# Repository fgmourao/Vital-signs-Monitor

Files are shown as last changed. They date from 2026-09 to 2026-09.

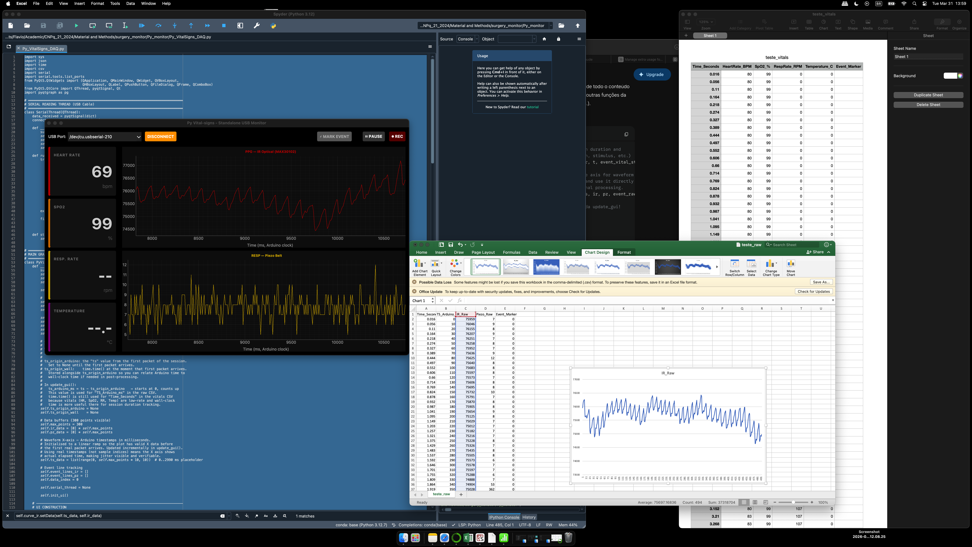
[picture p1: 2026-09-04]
Refs/interface_.png

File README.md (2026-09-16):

# Vital-signs Monitor v1.0
> **Under development**

Real-time, non-invasive physiological monitoring during experimental surgeries, stereotaxic procedures, and deep anaesthesia protocols in small rodents. ATmega2560 acquisition board controlled by a Python/PyQt5 application over USB, with simultaneous Wi-Fi browser dashboard via an on-board ESP8266.

---

## Overview

Four physiological parameters are acquired simultaneously:

- **Heart Rate** — MAX30102 optical sensor (IR channel), SparkFun `checkForBeat()` peak detector, rolling mean over N=6 beats
- **SpO2** — MAX30102 Red + IR channels, Maxim `spo2_algorithm` (sliding window: retain 75, refill 25 per update)
- **Respiratory Rate** — respiratory sensor at A0 (piezo film or FSR406 pressure sensor), software Schmitt trigger with adaptive envelope calibration every 2 s
- **Core Temperature** — NTC 100 kΩ rectal thermistor (A1), Beta equation conversion

All parameters are streamed at 100 Hz to the Python DAQ via USB-Serial and to a browser dashboard via WebSocket over Wi-Fi.

---

## Architecture

```
ATmega2560 (RobotDyn Mega+WiFi)
      │
      ├─ Serial0 (USB, 115200) ────────────────────────────────────────────────
      │        ↕ bidirectional JSON                                            │
      │   Py_VitalSigns_DAQ.py (PyQt5)                                        │
      │        outbound: {"hr":N,"sp":N,"rr":N,"pz":N,"t":N,"ir":N,"ts":N}   │
      │        inbound:  SOH + {"cmd":"set","key":"K","val":V}                 │
      │                  SOH + {"cmd":"get"}                                   │
      │                                                                        │
      ├─ Serial3 (pins 14/15, 115200) → ESP8266 (on-board) ──────────────────
      │        JSON 100 Hz stream → WebSocket → browser dashboard             │
      │                                                                        │
      ├─ I²C (pins 20/21)                                                     │
      │        ├─ MAX30102 optical sensor (address 0x57)                      │
      │        └─ SSD1306 OLED 128×32 (address 0x3C)                          │
      │                                                                        │
      ├─ A0 — Respiratory sensor (piezo film or FSR406 pressure sensor)       │
      ├─ A1 — NTC rectal thermistor                                            │
      │                                                                        │
      └─ Free-running ADC (~9.6 kHz) + TIMER1 CTC (100 Hz)                   │
               ISR decimation and Schmitt trigger for respiratory rate
```

---

## Signal Chain

### Heart Rate and SpO2

```
MAX30102 internal (400 Hz raw)
    └─ hardware averaging 4:1 → FIFO at 100 Hz
              │
              ├─ PATH 1 — Heart Rate
              │    checkForBeat(irRaw) at 100 Hz
              │    → _process_beat(): physiological gate + outlier rejection
              │    → rolling mean N=6 → heartRate (BPM)
              │
              └─ PATH 2 — SpO2
                   software decimation × g_DECIM_RATIO (default 1)
                   → irBuffer[100] + redBuffer[100]
                   → maxim_heart_rate_and_oxygen_saturation()
                   → sliding window (retain 75, refill 25) → spO2 (%)
```

### Respiratory Rate

```
Respiratory sensor (A0)
    └─ ADC_vect free-running ~9.6 kHz (ISR)
              └─ TIMER1_COMPA_vect 100 Hz CTC (ISR)
                       └─ N=4 moving average
                                └─ software Schmitt trigger
                                         └─ adaptive envelope calibration every 2 s
                                                  └─ respRate (rpm)
```

### Respiratory Sensor Signal Conditioning (Python)

The raw ADC counts from the respiratory sensor are processed in Python before display and CSV recording:

1. **Unit conversion** — counts → mV (10-bit ADC, 5 V reference: 1 count ≈ 4.89 mV)
2. **DC baseline removal** — IIR low-pass filter (α = 0.005 @ 100 Hz, fc ≈ 0.08 Hz) tracks slow drift from animal weight and posture. Time constant ~200 s.
3. **Polarity correction** — controlled by `_INVERT_RESP` constant:
   - `True` (default): FSR406 and piezo where inspiration causes a voltage drop
   - `False`: piezo where inspiration already produces a positive peak
4. **Resp. Tare** — forces immediate convergence of the DC estimate when the animal is placed on the sensor

The same processing is applied in the browser dashboard JavaScript.

### Temporal Alignment

Both `ir` and `pz` are packed in the same JSON packet. The `"ts"` field carries `millis()` at packet serialisation time and is used by the Python DAQ as the common X-axis for both waveforms, eliminating USB transport jitter (~1–15 ms) from the recorded data.

---

## EEPROM Persistence

All mutable parameters (`g_*` variables) are saved to EEPROM on every change and restored on power-up. The first boot after a fresh firmware upload uses compile-time defaults; subsequent boots load the last saved values.

EEPROM layout (ATmega2560, 4 KB available):

| Addr | Variable | Type | Bytes |
|---|---|---|---|
| 0 | Magic byte (0xA6) | uint8_t | 1 |
| 1 | g_HR_MIN_BPM | float | 4 |
| 5 | g_HR_MAX_BPM | float | 4 |
| 9 | g_HR_OUTLIER_FRAC | float | 4 |
| 13 | g_SPO2_MIN_VALID | uint8_t | 1 |
| 14 | g_DECIM_RATIO | uint8_t | 1 |
| 15 | g_LED_BRIGHTNESS | uint8_t | 1 |
| 16 | g_SAMPLE_AVERAGE | uint8_t | 1 |
| 17 | g_ADC_RANGE | uint32_t | 4 |
| 21 | g_PULSE_WIDTH | uint16_t | 2 |
| 23 | g_CALIB_MIN_SWING | int | 4 |
| 27 | g_THRESH_INSP_FRAC | float | 4 |
| 31 | g_THRESH_EXP_FRAC | float | 4 |
| 35 | g_TEMP_MIN_C | float | 4 |
| 39 | g_TEMP_MAX_C | float | 4 |

---

## USB Protocol

Bidirectional JSON over Serial0 (115200 baud). Python prefixes every command with SOH (0x01) to halt the outbound 100 Hz stream before sending.

```
Outbound (100 Hz):
    {"hr":N,"sp":N,"rr":N,"pz":N,"t":N.N,"ir":N,"ts":N}

Inbound — set parameter:
    SOH + {"cmd":"set","key":"HR_MAX","val":500} + \n
    → {"ack":"HR_MAX","val":500.0000}
    → {"nak":"reason"}  (on failure)

Inbound — read all parameters:
    SOH + {"cmd":"get"} + \n
    → {"ack":"HR_MIN","val":40.0000}
       {"ack":"HR_MAX","val":800.0000}
       ... (one line per parameter)
```

### Configurable Parameters

| Key | Variable | Module | Description |
|---|---|---|---|
| `HR_MIN` | g_HR_MIN_BPM | MAX30102 | HR lower physiological gate (BPM) |
| `HR_MAX` | g_HR_MAX_BPM | MAX30102 | HR upper physiological gate (BPM) |
| `HR_OUTLIER` | g_HR_OUTLIER_FRAC | MAX30102 | Outlier rejection fraction (0.10–0.70) |
| `SPO2_MIN` | g_SPO2_MIN_VALID | MAX30102 | Minimum accepted SpO2 (%) |
| `DECIM_RATIO` | g_DECIM_RATIO | MAX30102 | SpO2 software decimation (1, 2, or 4) |
| `LED` | g_LED_BRIGHTNESS | MAX30102 | LED drive current (1–255) — reruns sensor setup |
| `ADC_RANGE` | g_ADC_RANGE | MAX30102 | ADC full-scale (2048/4096/8192/16384) — reruns setup |
| `SAMPLE_AVG` | g_SAMPLE_AVERAGE | MAX30102 | Hardware averaging per FIFO entry — reruns setup |
| `PULSE_WIDTH` | g_PULSE_WIDTH | MAX30102 | LED pulse width (69/118/215/411 µs) — reruns setup |
| `CALIB_SWING` | g_CALIB_MIN_SWING | monitor | Minimum respiratory sensor swing (mV) for valid calibration |
| `THRESH_INSP` | g_THRESH_INSP_FRAC | monitor | Inspiration threshold fraction (0.40–0.85) |
| `THRESH_EXP` | g_THRESH_EXP_FRAC | monitor | Expiration threshold fraction (0.20–0.70) |
| `TEMP_MIN` | g_TEMP_MIN_C | monitor | Temperature lower physiological gate (°C) |
| `TEMP_MAX` | g_TEMP_MAX_C | monitor | Temperature upper physiological gate (°C) |

---

## Wi-Fi Dashboard

The ESP8266 creates a Wi-Fi access point (`SSID: Vital_Signs_Web_Monitor`) and serves an HTML dashboard at `http://192.168.4.1`. A WebSocket server on port 81 forwards the 100 Hz JSON stream to connected browsers. The browser applies the same respiratory signal conditioning as the Python DAQ (mV conversion, DC removal, polarity correction).

Multi-client dispatch:
- **Primary client** (first to connect): receives every packet → 100 Hz
- **Secondary clients** (subsequent): receive 1 in 4 packets → 25 Hz

---

## Python Application

### Requirements

```
pip install pyserial PyQt5 pyqtgraph scipy numpy
```

Python 3.8 or later. Compatible with Spyder IDE.

### Features

- Real-time scrolling waveform display (IR-PPG and respiratory sensor)
- Numeric readouts: HR, SpO2, respiratory rate, core temperature
- Arduino timestamp (`"ts"`) used as the common X-axis — eliminates USB transport jitter from recorded data
- **Settings panel** — runtime adjustment of all sensor and algorithm parameters without recompilation; changes saved to EEPROM automatically; values auto-synced from Arduino on connect
- **Help panel** — parameter reference with species-specific suggested values and tooltips on every field
- **FFT viewer** — live power spectral density for both IR-PPG and respiratory channels (Welch method, configurable window and segment length)
- **Resp. Tare** — instant respiratory sensor baseline zeroing; cancels animal weight offset without waiting for IIR filter convergence
- **Event marker** — intra-session surgical event marking with visual timeline markers on both waveforms
- **CSV recording** split into two files:
  - `*_vitals.csv` — low-rate physiological values, wall-clock time axis
  - `*_raw.csv` — high-rate conditioned waveform samples, Arduino timestamp axis (`TS_Arduino_ms`)
- Pause / Resume without disconnecting

### CSV Output Format

**`*_vitals.csv`**

| Column | Description |
|---|---|
| Time_Seconds | Wall-clock elapsed time since REC start (s) |
| HeartRate_BPM | HR from MAX30102 ring buffer (BPM) |
| SpO2_% | SpO2 from Maxim algorithm (%) |
| RespRate_RPM | Respiratory rate from sensor detector (rpm) |
| Temperature_C | NTC rectal temperature (°C) |
| Event_Marker | "Event Start" on marked rows |

**`*_raw.csv`**

| Column | Description |
|---|---|
| Time_Seconds | Wall-clock elapsed time — for cross-reference only |
| TS_Arduino_ms | Arduino millis(), normalised to 0 at REC start — **use this as the time axis for signal analysis** |
| IR_Raw | Raw IR count from MAX30102 FIFO (counts, 18-bit) |
| Resp_mV | Respiratory sensor signal in mV — DC-removed and polarity-corrected; inspiration = positive peak. NOT the raw ADC value. |
| Event_Marker | 1 on event rows, 0 otherwise |

---

## Respiratory Sensor

The system is compatible with two sensor types connected to A0 via a voltage divider (R_fixed in series to VCC):

| Sensor type | R_fixed | Notes |
|---|---|---|
| FSR406 pressure sensor | 10 kΩ | Set `_INVERT_RESP = True`. Place under the animal. Target DC ~2500 mV with animal weight. |
| Piezo film sensor | Depends on interface circuit | Set `_INVERT_RESP` based on observed polarity. Inherently AC — Resp. Tare less critical. |

**Optimal operating point:** DC level ≈ 2500 mV (mid-range) with the animal positioned. If DC is below 1000 mV, reduce R_fixed. If above 4000 mV, increase R_fixed. Adjust Calib Min Swing (default 586 mV) downward for animals with shallow breathing.

---

## Species Reference Values

| Parameter | Human (bench) | Rat (anaest.) | Mouse (anaest.) |
|---|---|---|---|
| HR Min | 40 BPM | 200 BPM | 250 BPM |
| HR Max | 200 BPM | 500 BPM | 800 BPM |
| LED Brightness | 80 | 40–60 | 20–40 |
| ADC Range | 16384 | 4096 | 2048–4096 |
| Sample Average | 4 | 1–4 | 1–2 |
| Pulse Width | 215 µs | 215–411 µs | 215–411 µs |

Target IR raw DC level: 50,000–130,000 counts (20–50% of ADC full-scale). Verify in the waveform plot after positioning the sensor.

---

## Design Tradeoffs

**[T1] DECIM_RATIO = 1**
The Maxim `spo2_algorithm.cpp` FIR filters were designed for 25 Hz input (DECIM_RATIO = 4). With DECIM_RATIO = 1 the algorithm receives 100 Hz. Human bench tests show physiologically correct SpO2 (97–99%). Performance at rodent cardiac frequencies (300–600 BPM) is untested — if systematic SpO2 overestimation (e.g. constant 100%) is observed, increase DECIM_RATIO to 4 via Settings.

**[T2] checkForBeat() with hardware-averaged signal**
The SparkFun `checkForBeat()` detector was calibrated for unaveraged signals. With `sampleAverage = 4` the AC component is smoothed before detection. If HR detection fails on rodents, reduce `sampleAverage` to 1 via Settings to restore full AC amplitude at 400 Hz.

**[T3] ADC Range**
`adcRange = 16384` is required for human fingertip at LED = 80 to avoid saturation (IR DC reaches 262,143 = 18-bit ceiling). For rodent thin tissue, try `adcRange = 4096` and verify IR raw in the waveform plot.

**[T4] IIR DC baseline convergence**
The respiratory signal DC filter has a time constant of ~200 s at 100 Hz. When the animal is first placed on the sensor, the display may appear shifted until the filter converges. Use **Resp. Tare** to force immediate convergence.

**[T5] SparkFun library internal buffer — STORAGE_SIZE**
The SparkFun MAX3010x library uses an internal ring buffer (`STORAGE_SIZE`) to hold FIFO data between `check()` calls. The default value of 4 samples causes silent data loss whenever `loop()` is delayed beyond ~40 ms (e.g. by the OLED display task), producing irregular sample spacing in `irBuffer[]` and `redBuffer[]`. This distorts the Maxim FIR filters and typically causes SpO2 to read 100% or HR to be erratic. This project set `STORAGE_SIZE = 64` by editing `MAX30105.h` at `~/Documents/Arduino/libraries/SparkFun_MAX3010x_Sensor_Library/src/MAX30105.h`

**[T6] SpO2 reference values**
The Maxim `spo2_algorithm` lookup table was calibrated for adult human fingertip measurements. In anaesthetised rodents, SpO2 values of 88–95% have been reported in the literature. If the monitor reads 99–100% during rodent anaesthesia, this may reflect algorithm miscalibration (next steps...)

---

## Hardware Requirements

| Component | Specification |
|---|---|
| Microcontroller | RobotDyn Mega+WiFi (ATmega2560 + ESP8266) |
| Optical sensor | MAX30102 breakout — I²C, address 0x57, 3.3 V |
| Display | SSD1306 OLED 128×32 — I²C, address 0x3C |
| Respiratory sensor | Piezo film or FSR406 → A0 (voltage divider with R_fixed to VCC) |
| Temperature probe | NTC 100 kΩ rectal thermistor → A1 (series 100 kΩ to VCC) |
| USB | ATmega2560 USB-Serial bridge (Arduino IDE upload port) |

---

## Files

| File | Description |
|---|---|
| `surgery_monitor.ino` | Main sketch — ISRs, task scheduler, OLED display, monitor_set_param() |
| `surgery_monitor_MAX30102.ino` | MAX30102 HR + SpO2, EEPROM persistence, max30102_set_param() |
| `Py_Vital-Signs.ino` | USB bidirectional stream — 100 Hz outbound + SOH command parser |
| `surgery_monitor_web_server.ino` | Serial3 → ESP8266 JSON bridge at 100 Hz |
| `ESP8266_VitalSigns_Server.ino` | ESP8266 firmware — Wi-Fi AP, HTTP dashboard, WebSocket multi-client |
| `MAX30102_Diagnostic_Tool.ino` | Standalone diagnostic sketch — IR waveform and SpO2 algorithm analysis |
| `Py_VitalSigns_DAQ.py` | Python DAQ application (PyQt5 + pyqtgraph) |
| `fft_vitalsigns.py` | Live PSD viewer — Welch method for HR and respiratory spectral analysis |

Arduino library dependencies (install via Arduino IDE Library Manager):
- **SparkFun MAX3010x Pulse and Proximity Sensor Library** ⚠️ requires manual modification (see [T5])
- **U8g2** (Oliver Kraus)
- **WebSockets** (Markus Sattler) — ESP8266 only

### Library Configuration

The SparkFun MAX3010x library requires one manual edit before compiling:

**File:** `~/Documents/Arduino/libraries/SparkFun_MAX3010x_Sensor_Library/src/MAX30105.h`

Locate and change:
```cpp
#define STORAGE_SIZE 4
```
to:
```cpp
#define STORAGE_SIZE 64  // required — default of 4 causes silent sample loss
```

This setting controls the size of the library's internal ring buffer. With the default of 4, any `loop()` delay beyond ~40 ms silently discards samples before they reach the HR and SpO2 algorithms, causing SpO2 to read 100% and HR to be erratic. See [T5] for the technical explanation.

---

## Known Limitations

- HR and SpO2 values are not validated against a calibrated reference instrument.
- SpO2 may read 100% consistently if `DECIM_RATIO = 1` (increase to 4 via Settings) or if the SparkFun library `STORAGE_SIZE` is not set to 64 (see [T5]).
- The `_debug_serial()` diagnostic output is plain text and incompatible with the Python DAQ. Use only with the Arduino IDE Serial Monitor when the Python application is not connected.
- If the USB cable is disconnected during a recording session, the CSV files may be incomplete. Always stop recording before disconnecting.
- Primary Wi-Fi client assignment is first-connect order. If a secondary workstation connects before the primary, it will receive 25 Hz instead of 100 Hz.
- The Resp. Tare is session-only — it resets if the application is restarted or the connection is toggled.

---

## Author

**v1.0 (2026)**
Flavio Afonso Goncalves Mourao — [mourao.fg@gmail.com](mailto:mourao.fg@gmail.com)
*CNPq/MCTI/FNDCT Nº 21/2024 — Processo 446467/2024-3*
*Federal University of Minas Gerais, Brazil*

---

*Last update: September 2026*

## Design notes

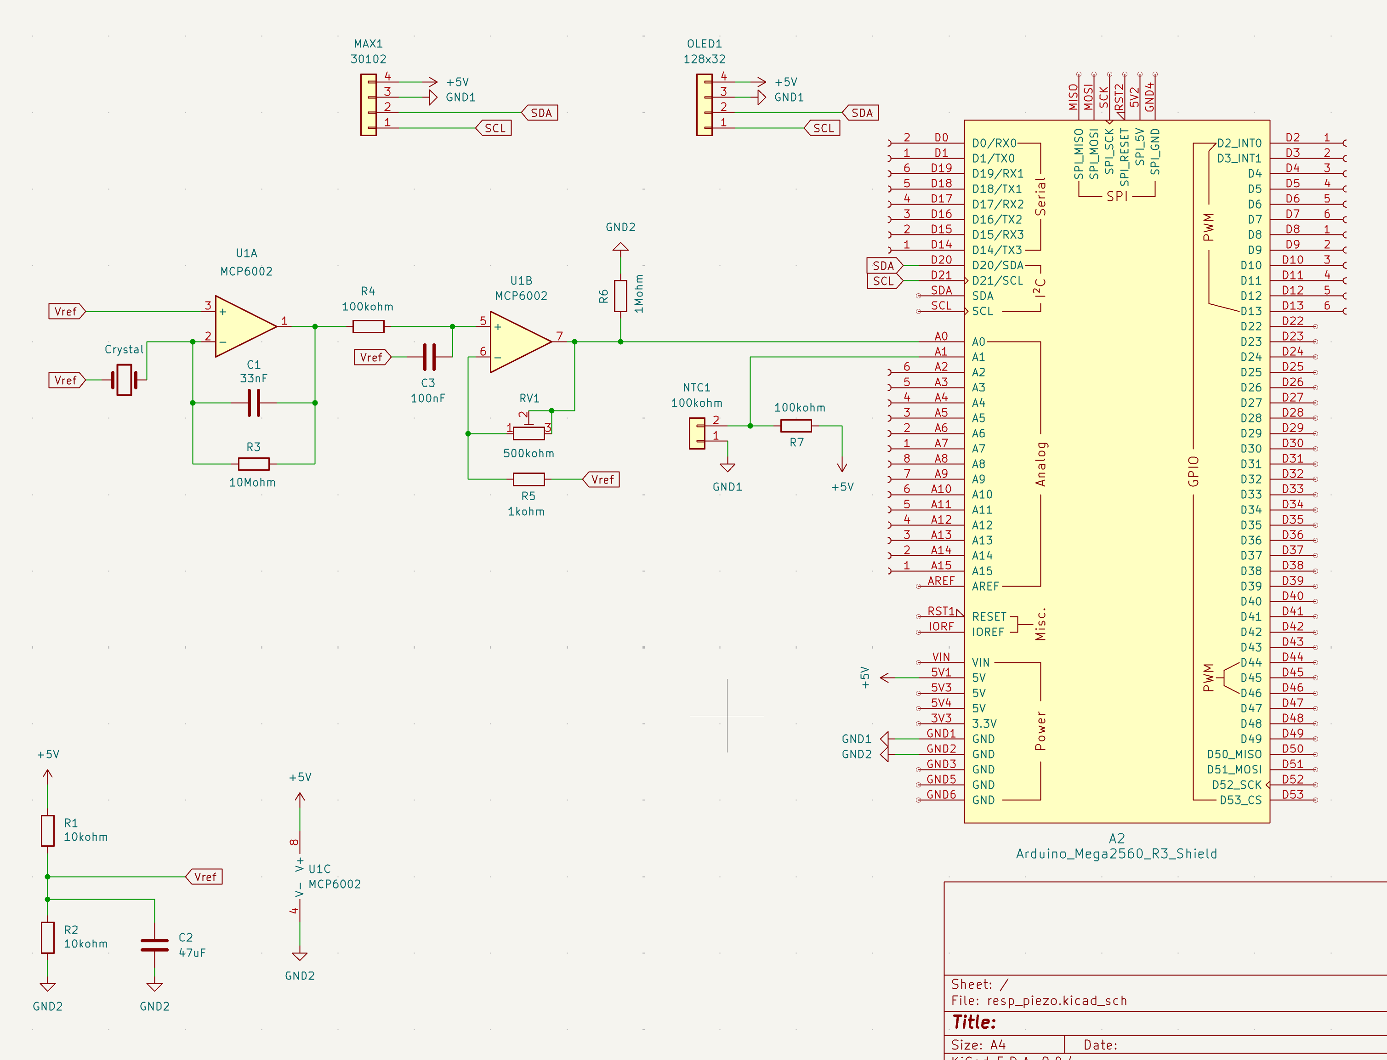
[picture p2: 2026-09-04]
Resp_piezo_circuit/Circuit_.png

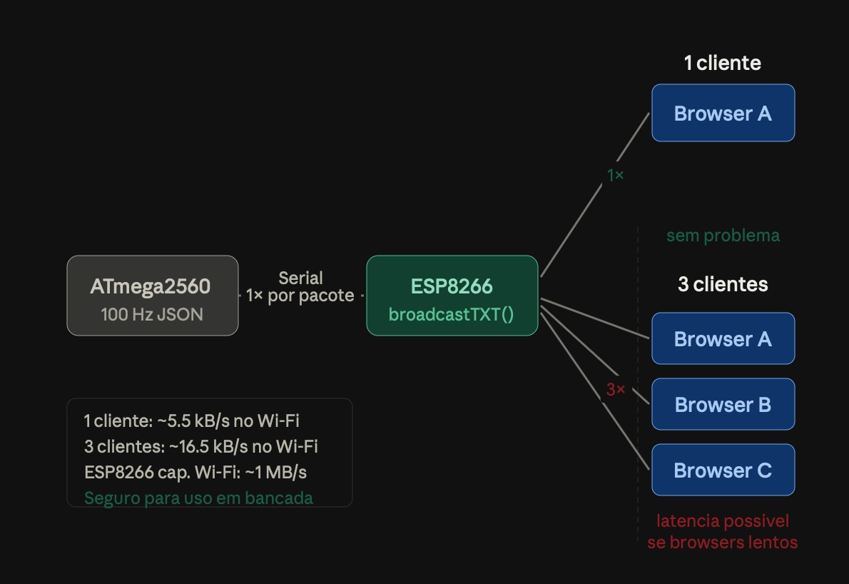
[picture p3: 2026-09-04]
Refs/ESP_client.png

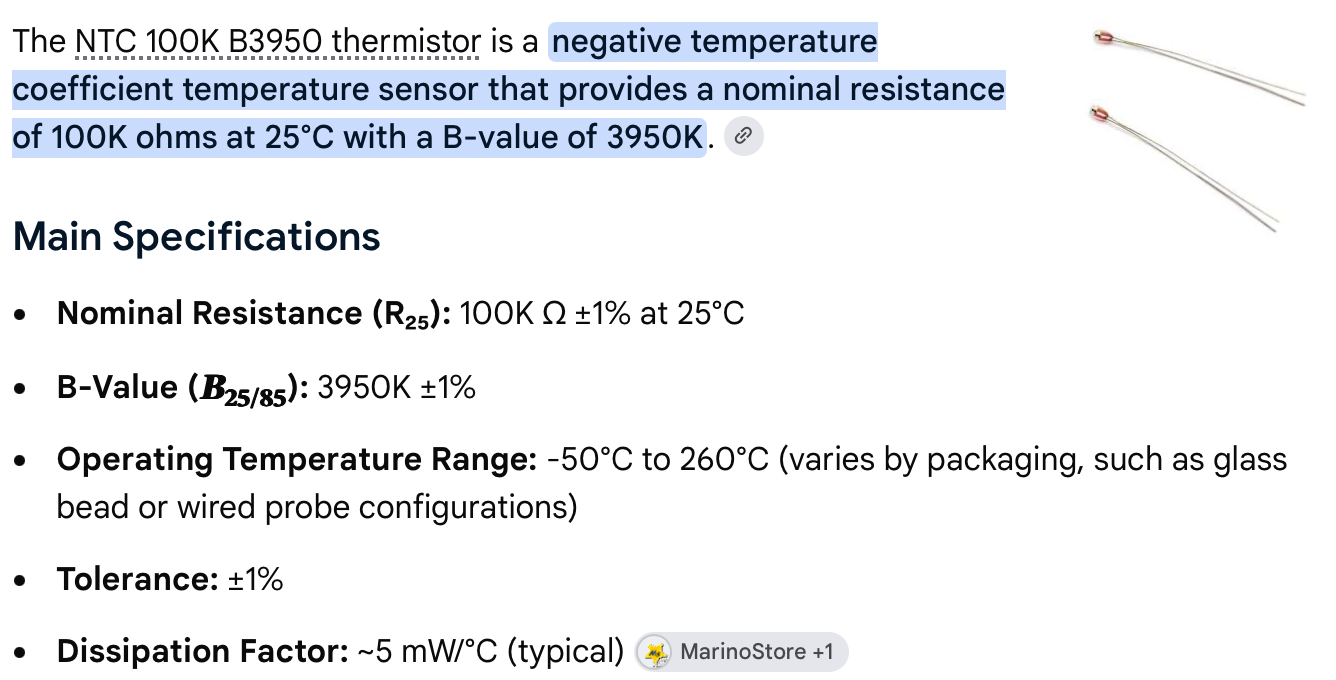
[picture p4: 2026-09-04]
Refs/Termistor NTC B3950 100K .png

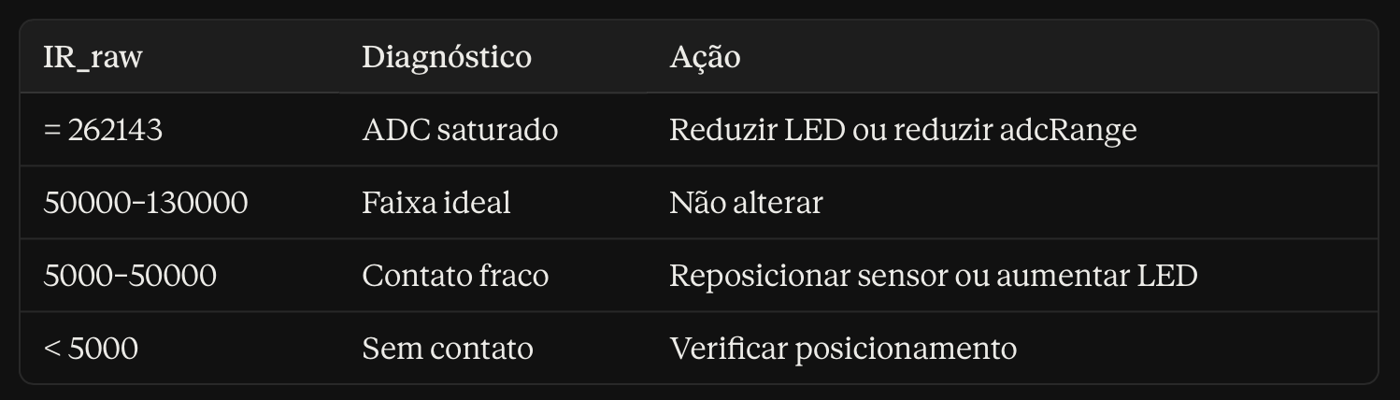
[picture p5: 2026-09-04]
Refs/IR_value.png

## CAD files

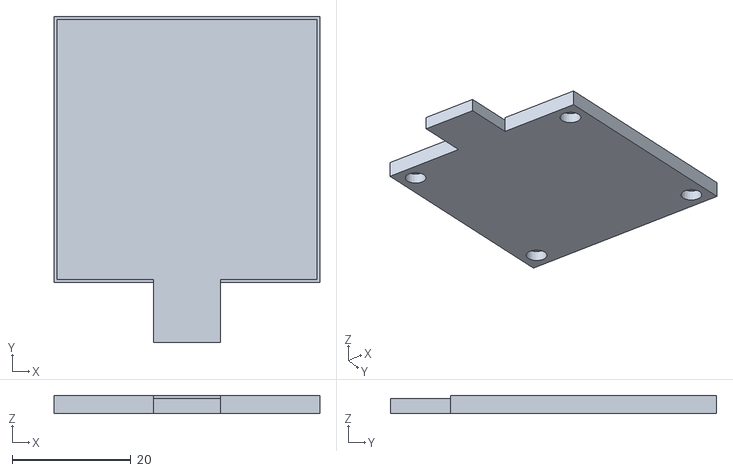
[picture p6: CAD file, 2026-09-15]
MAX30102_3D_case/FSR406/FSR406_base_magnets.stl
44.7 x 54.8 x 3.04

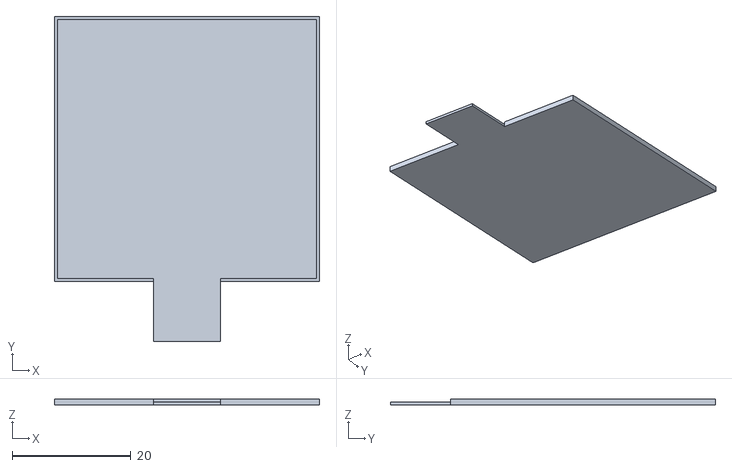
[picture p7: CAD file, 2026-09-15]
MAX30102_3D_case/FSR406/FSR406_base_thin.stl
44.7 x 54.8 x 1.04

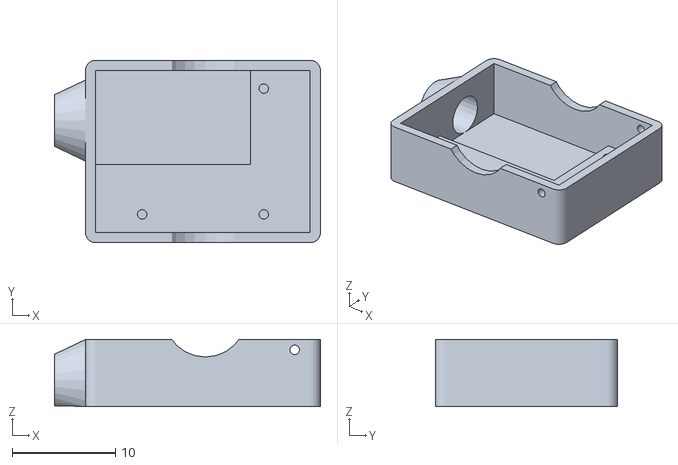
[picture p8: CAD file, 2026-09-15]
MAX30102_3D_case/MAX30102/MAX30102_case_bottom.stl
25.8 x 17.7 x 6.50

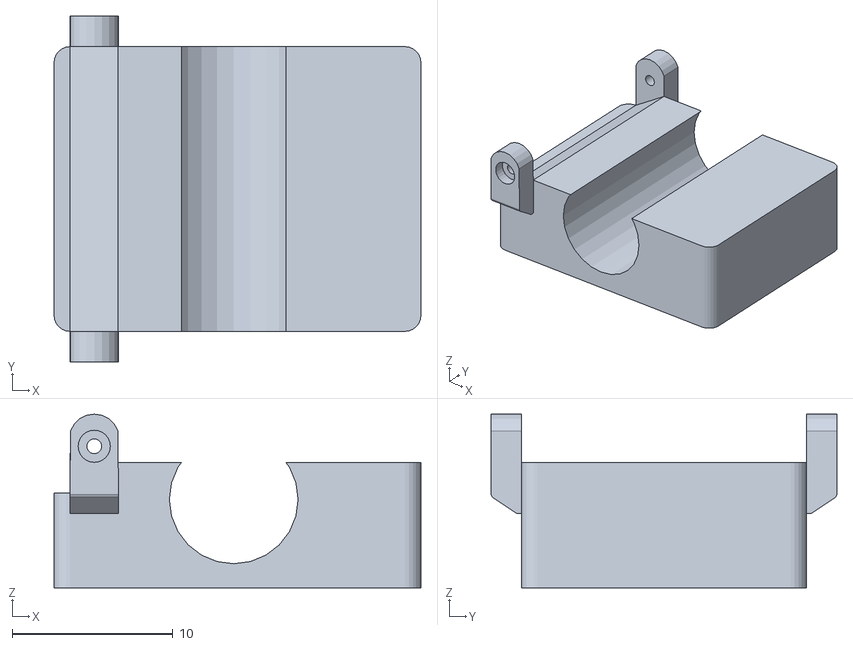
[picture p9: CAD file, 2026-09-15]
MAX30102_3D_case/MAX30102/MAX30102_case_top.stl
22.8 x 21.5 x 10.8

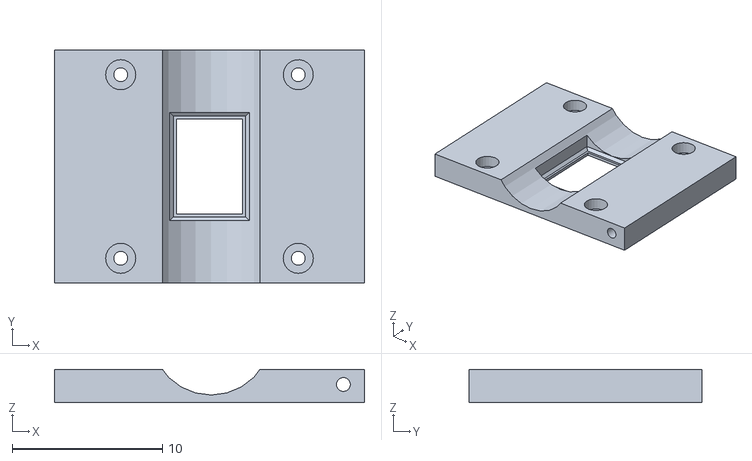
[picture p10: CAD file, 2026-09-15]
MAX30102_3D_case/MAX30102/MAX30102_case_middle.stl
20.6 x 15.5 x 2.20

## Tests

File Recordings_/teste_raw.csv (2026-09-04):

Time_Seconds | TS_Arduino_ms | IR_Raw | Piezo_Raw | Event_Marker
0.016 | 0 | 75959 | 7 | 0
0.056 | 10 | 76046 | 9 | 0
0.11 | 20 | 76155 | 8 | 0
0.164 | 30 | 76207 | 9 | 0
0.218 | 40 | 76251 | 7 | 0
0.274 | 50 | 76258 | 8 | 0
0.327 | 60 | 75952 | 7 | 0
0.389 | 70 | 75636 | 9 | 0
0.444 | 80 | 75625 | 12 | 0
0.497 | 90 | 75640 | 8 | 0
0.552 | 100 | 75683 | 8 | 0
0.606 | 110 | 75597 | 8 | 0
0.66 | 120 | 75573 | 7 | 0
0.714 | 130 | 75606 | 8 | 0
0.769 | 140 | 75695 | 8 | 0
0.824 | 150 | 75732 | 10 | 0
0.878 | 160 | 75791 | 7 | 0
0.932 | 170 | 75870 | 8 | 0
0.987 | 180 | 75905 | 8 | 0
1.041 | 190 | 75654 | 9 | 0
1.095 | 200 | 75125 | 8 | 0
1.149 | 210 | 75029 | 7 | 0
1.203 | 220 | 75012 | 7 | 0
1.257 | 230 | 75182 | 7 | 0
1.321 | 240 | 75216 | 7 | 0
1.375 | 250 | 75228 | 8 | 0
1.429 | 260 | 75326 | 7 | 0
1.483 | 270 | 75435 | 8 | 0
1.537 | 280 | 75505 | 8 | 0
1.592 | 290 | 75573 | 6 | 0
1.646 | 300 | 75578 | 7 | 0
1.701 | 310 | 75597 | 7 | 0
1.755 | 320 | 75288 | 6 | 0
1.809 | 330 | 74888 | 7 | 0
1.864 | 340 | 74904 | 53 | 0
1.919 | 350 | 75028 | 362 | 0
1.973 | 360 | 75218 | 453 | 0
2.027 | 370 | 75197 | 747 | 0
2.082 | 380 | 75194 | 751 | 0
2.136 | 390 | 75310 | 753 | 0
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

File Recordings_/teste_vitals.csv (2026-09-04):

Time_Seconds | HeartRate_BPM | SpO2_% | RespRate_RPM | Temperature_C | Event_Marker
0.016 | 80 | 99 | 0 | 0
0.056 | 80 | 99 | 0 | 0
0.11 | 80 | 99 | 0 | 0
0.164 | 80 | 99 | 0 | 0
0.218 | 80 | 99 | 0 | 0
0.274 | 80 | 99 | 0 | 0
0.327 | 80 | 99 | 0 | 0
0.389 | 80 | 99 | 0 | 0
0.444 | 80 | 99 | 0 | 0
0.497 | 80 | 99 | 0 | 0
0.552 | 80 | 99 | 0 | 0
0.606 | 80 | 99 | 0 | 0
0.66 | 80 | 99 | 0 | 0
0.714 | 80 | 99 | 0 | 0
0.769 | 80 | 99 | 0 | 0
0.824 | 80 | 99 | 0 | 0
0.878 | 80 | 99 | 0 | 0
0.932 | 80 | 99 | 0 | 0
0.987 | 80 | 99 | 0 | 0
1.041 | 80 | 99 | 0 | 0
1.095 | 80 | 99 | 0 | 0
1.149 | 80 | 99 | 0 | 0
1.203 | 80 | 99 | 0 | 0
1.257 | 80 | 99 | 0 | 0
1.321 | 80 | 99 | 0 | 0
1.375 | 80 | 99 | 0 | 0
1.429 | 80 | 99 | 0 | 0
1.483 | 80 | 99 | 0 | 0
1.537 | 80 | 99 | 0 | 0
1.592 | 80 | 99 | 0 | 0
1.646 | 80 | 99 | 0 | 0
1.701 | 80 | 99 | 0 | 0
1.755 | 80 | 99 | 0 | 0
1.809 | 80 | 99 | 0 | 0
1.864 | 80 | 99 | 0 | 0
1.919 | 80 | 99 | 0 | 0
1.973 | 80 | 99 | 0 | 0
2.027 | 80 | 99 | 0 | 0
2.082 | 80 | 99 | 0 | 0
2.136 | 80 | 99 | 0 | 0
2.19 | 80 | 99 | 0 | 0
2.252 | 80 | 99 | 0 | 0
2.306 | 80 | 99 | 0 | 0
2.362 | 80 | 99 | 0 | 0
2.416 | 80 | 99 | 0 | 0
2.471 | 80 | 99 | 0 | 0
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

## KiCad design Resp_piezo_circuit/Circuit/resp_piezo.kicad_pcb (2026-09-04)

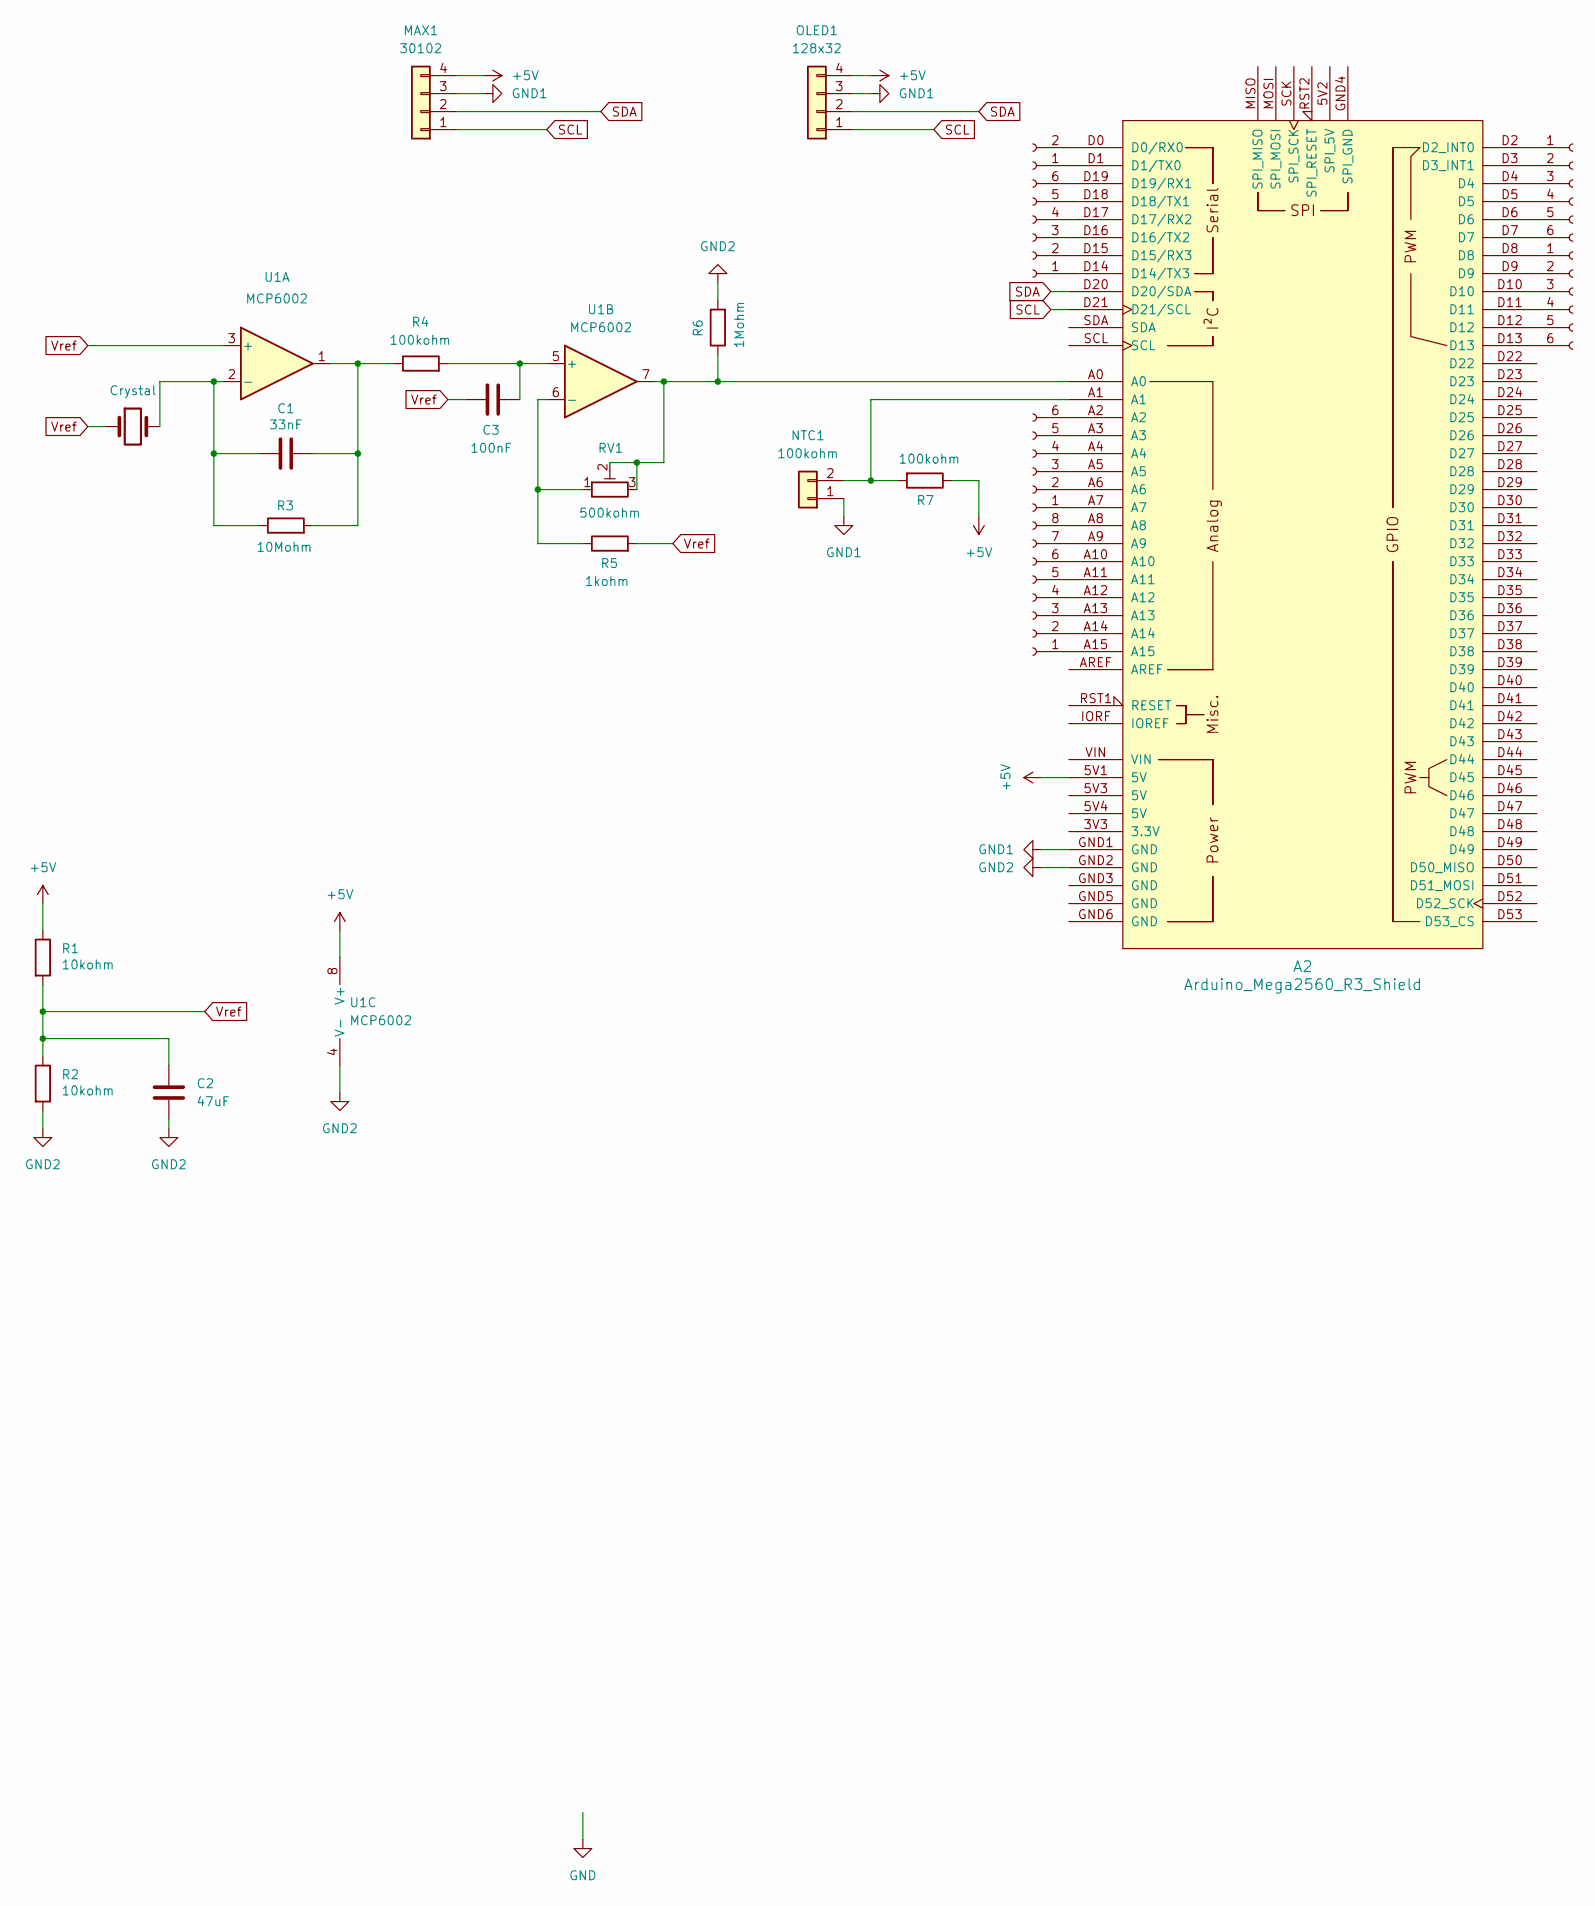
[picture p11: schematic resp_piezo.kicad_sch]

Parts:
A2: Arduino_Mega2560_R3_Shield
C1: 33nF; C_0805_2012Metric
C2: 47uF; C_0805_2012Metric
C3: 100nF; C_0805_2012Metric
J1, J3, J4: Conn_01x06_Socket; PinSocket_1x06_P2.54mm_Vertical
J2: Conn_01x06_Socket; PinHeader_1x06_P2.54mm_Vertical
J5: Conn_01x08_Socket; PinHeader_1x08_P2.00mm_Vertical
J6: Conn_01x02_Socket; PinSocket_1x02_P2.00mm_Vertical
MAX1: 30102; PinSocket_1x04_P2.54mm_Vertical
NTC1: 100kohm; PinSocket_1x02_P2.54mm_Vertical
OLED1: 128x32; PinSocket_1x04_P2.54mm_Vertical
R1, R2: 10kohm; R_0805_2012Metric
R3: 10Mohm; R_0805_2012Metric
R4, R7: 100kohm; R_0805_2012Metric
R5: 1kohm; R_0805_2012Metric
R6: 1Mohm; R_0805_2012Metric
RV1: 500kohm; PinHeader_1x03_P2.54mm_Vertical
U1: MCP6002; DIP787W46P254L927H533Q8
Y1: Crystal; PinHeader_1x02_P2.54mm_Vertical

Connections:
+5V: A2.5V1 (5V), MAX1.4, OLED1.4, R1.1, R7.1, U1.8 (V+)
GND1: A2.GND1 (GND), MAX1.3, NTC1.1, OLED1.3
GND2: A2.GND2 (GND), C2.2, R2.2, R6.2, U1.4 (V-), U1.9 (V-)
unnamed: A2.D0 (D0/RX0), J6.2
unnamed: A2.D1 (D1/TX0), J6.1
unnamed: A2.D2 (D2_INT0), J1.1
unnamed: A2.D3 (D3_INT1), J1.2
unnamed: A2.D14 (D14/TX3), J3.1
unnamed: A2.D15 (D15/RX3), J3.2
unnamed: A2.D16 (D16/TX2), J3.3
unnamed: A2.D17 (D17/RX2), J3.4
unnamed: A2.D18 (D18/TX1), J3.5
unnamed: A2.D19 (D19/RX1), J3.6
unnamed: A2.A0, R6.1, RV1.2, RV1.3, U1.7
unnamed: C1.2, R3.2, R4.1, U1.1
unnamed: A2.D4, J1.3
unnamed: A2.D5, J1.4
unnamed: A2.D6, J1.5
unnamed: A2.D7, J1.6
unnamed: A2.D8, J2.1
unnamed: A2.D9, J2.2
unnamed: A2.D10, J2.3
unnamed: A2.D11, J2.4
unnamed: A2.D12, J2.5
unnamed: A2.D13, J2.6
unnamed: A2.A7, J4.1
unnamed: A2.A6, J4.2
unnamed: A2.A5, J4.3
unnamed: A2.A4, J4.4
unnamed: A2.A3, J4.5
unnamed: A2.A2, J4.6
unnamed: A2.A15, J5.1
unnamed: A2.A14, J5.2
unnamed: A2.A13, J5.3
unnamed: A2.A12, J5.4
unnamed: A2.A11, J5.5
unnamed: A2.A10, J5.6
unnamed: A2.A9, J5.7
unnamed: A2.A8, J5.8
unnamed: A2.A1, NTC1.2, R7.2
unnamed: C1.1, R3.1, U1.2 (-), Y1.2
unnamed: C3.2, R4.2, U1.5 (+)
unnamed: R5.1, RV1.1, U1.6 (-)
SCL: A2.D21 (D21/SCL), MAX1.1, OLED1.1
SDA: A2.D20 (D20/SDA), MAX1.2, OLED1.2
Vref: C2.1, C3.1, R1.2, R2.1, R5.2, U1.3 (+), Y1.1

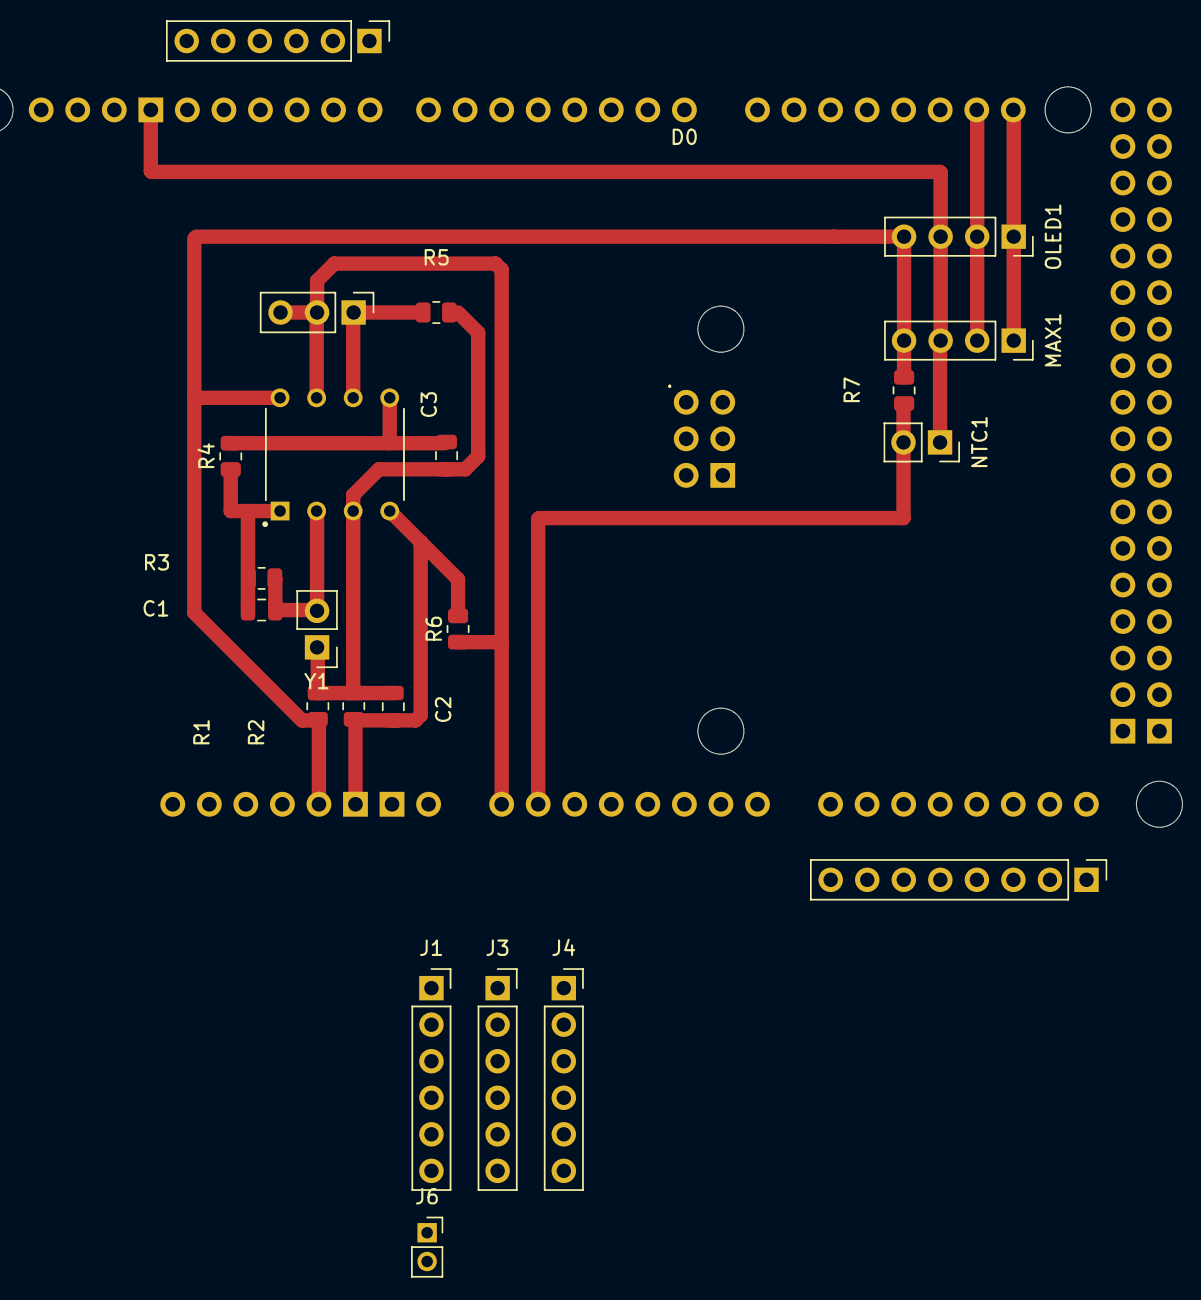
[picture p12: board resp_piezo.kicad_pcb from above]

Board: 2 copper layers, 23 parts (0 on the bottom side), 46 nets.

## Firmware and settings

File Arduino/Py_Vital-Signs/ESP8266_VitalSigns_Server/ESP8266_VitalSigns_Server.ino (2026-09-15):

/**
 * @file    ESP8266_VitalSigns_Server.ino
 * PROJECT: Vital-signs monitor — small rodents (rat / mouse)
 * @version 3.0 (Multi-client)
 * @author  Flávio Mourão — Mar, 2026
 *
 * ═══════════════════════════════════════════════════════════════════════════════
 * MODULE RESPONSIBILITY
 * ═══════════════════════════════════════════════════════════════════════════════
 * This sketch runs on the ESP8266 co-processor of the RobotDyn Mega+WiFi board.
 * It performs three tasks:
 *
 *   1. Wi-Fi Access Point — creates a local network (no internet required).
 *   2. HTTP Server (port 80) — serves the embedded HTML/JS dashboard to browsers.
 *   3. WebSocket Server (port 81) — forwards JSON packets received from the
 *      ATmega2560 (via Serial) to connected browser clients.
 *
 * ═══════════════════════════════════════════════════════════════════════════════
 * CHANGES vs v2.0 — MULTI-CLIENT SUPPORT (3–5 simultaneous browsers)
 * ═══════════════════════════════════════════════════════════════════════════════
 *
 * [C1] Non-blocking Serial read (replaces readStringUntil)
 *   v2.0 used Serial.readStringUntil('\n'), which blocks the entire loop()
 *   until a full line arrives or the timeout expires. With multiple WebSocket
 *   clients generating keep-alive traffic, this caused frame accumulation and
 *   eventually client disconnections.
 *
 *   v3.0 reads one byte at a time per loop() iteration, accumulating into
 *   rxBuffer until '\n' is detected. webSocket.loop() is never blocked.
 *   Maximum latency added per loop(): one Serial.read() call (~1 µs).
 *
 * [C2] Tiered dispatch: primary client at 100 Hz, secondary clients at 25 Hz
 *   Broadcasting the full 100 Hz stream to 5 clients simultaneously would
 *   require the ESP8266 to transmit 5 × 55 bytes × 100 Hz = 27.5 kB/s on
 *   the Wi-Fi channel. While within the hardware limit (~1 MB/s), the
 *   sequential sendTXT() calls per loop() iteration would block webSocket.loop()
 *   for ~2.4 ms at 115200 baud, degrading all clients.
 *
 *   The tiered approach:
 *     Primary client (first to connect): receives every packet → 100 Hz
 *     Secondary clients (subsequent):   receive 1 in 4 packets → 25 Hz
 *
 *   25 Hz is sufficient for numeric readout updates and smooth waveform
 *   display on secondary monitors (human visual persistence ~40 ms).
 *   The primary client (e.g., the surgeon's workstation) retains full
 *   100 Hz resolution for waveform detail.
 *
 * [C3] WebSocket event handler
 *   webSocket.onEvent() now tracks which client is the primary and clears
 *   the slot when the primary disconnects, allowing the next client to
 *   take the primary role automatically.
 *
 * ═══════════════════════════════════════════════════════════════════════════════
 * HARDWARE CONTEXT — RobotDyn Mega+WiFi
 * ═══════════════════════════════════════════════════════════════════════════════
 * On the RobotDyn board, the ESP8266 hardware UART (Serial, GPIO1/GPIO3) is
 * bridged via PCB traces to ATmega2560 Serial3 (pins 14/15). Data flows:
 *
 *   ATmega2560 Serial3 → [PCB bridge] → ESP8266 Serial.available()
 *
 * Baud rate: 115200. Must match vitalsigns_init() in surgery_monitor_web_server.ino.
 *
 * Flash this sketch using the Arduino IDE with board set to "Generic ESP8266".
 * The DIP switch bank on the RobotDyn board must be configured for ESP8266
 * programming mode during upload, then switched back for normal Mega operation.
 *
 * ═══════════════════════════════════════════════════════════════════════════════
 * NETWORK ARCHITECTURE
 * ═══════════════════════════════════════════════════════════════════════════════
 *
 *  [ATmega2560] --Serial3/115200--> [ESP8266] --Wi-Fi AP--> [Browsers]
 *
 *  Access Point:  SSID = AP_SSID (default: "Vital_Signs_Web_Monitor")
 *  Password:      AP_PASSWORD (empty = open network)
 *  AP IP address: 192.168.4.1 (ESP8266 SoftAP default)
 *
 *  Browser access: http://192.168.4.1
 *  WebSocket:      ws://192.168.4.1:81
 *
 *  Client capacity: up to WEBSOCKETS_SERVER_CLIENT_MAX (default 5 in library).
 *    - Client 0 (primary):   100 Hz full stream
 *    - Clients 1–4 (secondary): 25 Hz reduced stream
 *
 * ═══════════════════════════════════════════════════════════════════════════════
 * BANDWIDTH BUDGET (worst case: 5 clients)
 * ═══════════════════════════════════════════════════════════════════════════════
 *  Primary (1×):    65 B × 100 Hz = 6.5 kB/s
 *  Secondary (4×):  65 B × 25 Hz × 4 = 26 kB/s
 *  Total:           ~32.5 kB/s << ESP8266 Wi-Fi ~1 MB/s capacity
 *
 * ═══════════════════════════════════════════════════════════════════════════════
 * KNOWN LIMITATIONS
 * ═══════════════════════════════════════════════════════════════════════════════
 * [L1] Primary client assignment is first-connect order
 *   The first browser to open a WebSocket connection becomes the primary
 *   (100 Hz) client. If the surgeon's workstation connects second, it
 *   receives 25 Hz. Workaround: reload the primary browser first, or
 *   implement a URL parameter to request primary status (e.g. /?primary=1).
 *
 * [L2] Open Wi-Fi network
 *   AP_PASSWORD is empty by default — open network. Acceptable in a
 *   controlled lab. Set WPA2 password for environments with data governance
 *   requirements.
 *
 * [L3] No data persistence
 *   The ESP8266 holds no historical data. A browser connecting mid-session
 *   starts with an empty waveform buffer and sees no past data.
 *
 * ═══════════════════════════════════════════════════════════════════════════════
 * REQUIRED LIBRARIES
 * ═══════════════════════════════════════════════════════════════════════════════
 *   ESP8266WiFi       — bundled with ESP8266 Arduino core
 *   ESP8266WebServer  — bundled with ESP8266 Arduino core
 *   WebSocketsServer  — arduinoWebSockets by Markus Sattler (Library Manager)
 */

#include <ESP8266WiFi.h>
#include <ESP8266WebServer.h>
#include <WebSocketsServer.h>


// ── Network configuration ────────────────────────────────────────────────────

const char* AP_SSID     = "Vital_Signs_Web_Monitor";
const char* AP_PASSWORD = "";   // Empty = open network


// ── Multi-client configuration ───────────────────────────────────────────────

// Maximum clients the WebSocketsServer library supports simultaneously.
// Default in the library: 5. Increase by editing WEBSOCKETS_SERVER_CLIENT_MAX
// in WebSockets.h, but each slot consumes ~300 B of heap on the ESP8266.
static const uint8_t MAX_CLIENTS = 5;

// Rate divisor for secondary clients.
// SECONDARY_DIVISOR = 4 → secondary clients receive 1 in 4 packets = 25 Hz.
// Increase to 8 for 12.5 Hz if more than 4 secondary clients are expected.
static const uint8_t SECONDARY_DIVISOR = 4;

// Sentinel value: no primary client assigned yet.
static const uint8_t NO_PRIMARY = 255;


// ── Runtime state ────────────────────────────────────────────────────────────

// ID of the primary (100 Hz) WebSocket client.
// Set to the first client that connects; reset when that client disconnects.
static uint8_t primaryClientId = NO_PRIMARY;

// Packet counter used to throttle secondary clients.
// Incremented on every valid packet received from the ATmega2560.
static uint8_t packetCount = 0;

// Non-blocking Serial receive buffer.
// Accumulates bytes until '\n' is received, then dispatches the complete packet.
static String rxBuffer = "";


// ── Server instances ─────────────────────────────────────────────────────────

ESP8266WebServer  server(80);
WebSocketsServer  webSocket = WebSocketsServer(81);


// ── Embedded dashboard HTML/JS ───────────────────────────────────────────────
// Stored in PROGMEM (flash) to preserve heap RAM.
// Identical to v2.0 — the multi-client logic is server-side only.
// Secondary clients display at 25 Hz; all visual behaviour is unchanged.
const char index_html[] PROGMEM = R"rawliteral(
<!DOCTYPE html>
<html lang="en">
<head>
    <meta charset="UTF-8">
    <meta name="viewport" content="width=device-width, initial-scale=1.0">
    <title>Vital-Signs - Web Monitor</title>
    <style>
        * { box-sizing: border-box; margin: 0; padding: 0; }
        body { background-color: #000; color: #fff; font-family: 'Segoe UI', Tahoma, Geneva, Verdana, sans-serif; overflow: hidden; height: 100vh; }
        #header { background: #111; padding: 8px 20px; font-size: 18px; font-weight: bold; border-bottom: 2px solid #222; color: #666; display: flex; align-items: center; gap: 10px; height: 42px; }
        #status-dot { width: 10px; height: 10px; border-radius: 50%; background: #333; flex-shrink: 0; }
        #status-dot.connected { background: #0f0; }
        #client-role { font-size: 12px; color: #444; margin-left: auto; }
        .grid-container { display: flex; height: calc(100vh - 42px); }
        .sidebar { width: 260px; min-width: 200px; background: #0a0a0a; padding: 16px; display: flex; flex-direction: column; gap: 14px; border-right: 2px solid #1a1a1a; overflow: hidden; }
        .box { background: #111; padding: 12px 14px; border-radius: 8px; border-left: 5px solid; flex: 1; }
        
        .box.hr   { border-color: #b30000; color: #ccc; }
        .box.spo2 { border-color: #cc6600; color: #ccc; }
        .box.rr   { border-color: #cca300; color: #ccc; }
        .box.temp { border-color: #800080; color: #ccc; }

        .label { font-size: 11px; text-transform: uppercase; letter-spacing: 1.5px; color: #666; margin-bottom: 4px; }
        .value { font-size: 52px; font-weight: bold; text-align: right; line-height: 1; }
        .unit { font-size: 16px; color: #444; }
        .main-content { flex-grow: 1; padding: 14px; display: flex; flex-direction: column; gap: 14px; overflow: hidden; }
        .chart-container { flex: 1; background: #0d0d0d; border-radius: 8px; border: 1px solid #1a1a1a; position: relative; padding: 8px; overflow: hidden; }
        .chart-title { position: absolute; top: 8px; left: 12px; font-size: 11px; color: #444; font-weight: bold; letter-spacing: 1px; text-transform: uppercase; pointer-events: none; }
        canvas { display: block; width: 100%; height: 100%; }
    </style>
</head>
<body>
    <div id="header">
        <div id="status-dot"></div>
        VITAL-SIGNS - WEB MONITOR
        <span id="client-role"></span>
    </div>
    <div class="grid-container">
        <div class="sidebar">
            <div class="box hr">
                <div class="label">Heart Rate</div>
                <div class="value" id="val_hr">-- <span class="unit">bpm</span></div>
            </div>
            <div class="box spo2">
                <div class="label">SpO2</div>
                <div class="value" id="val_spo2">-- <span class="unit">%</span></div>
            </div>
            <div class="box rr">
                <div class="label">Resp. Rate</div>
                <div class="value" id="val_rr">-- <span class="unit">rpm</span></div>
            </div>
            <div class="box temp">
                <div class="label">Temperature</div>
                <div class="value" id="val_temp">--.- <span class="unit">°C</span></div>
            </div>
        </div>
        <div class="main-content">
            <div class="chart-container">
                <div class="chart-title" style="color:#b30000;">Photoplethysmography</div>
                <canvas id="canvas_ir"></canvas>
            </div>
            <div class="chart-container">
                <div class="chart-title" style="color:#cca300;">Respiratory Excursions</div>
                <canvas id="canvas_resp"></canvas>
            </div>
        </div>
    </div>

    <script>
        const maxPoints = 300;
        let bufIR    = new Array(maxPoints).fill(0);
        let bufResp = new Array(maxPoints).fill(0);

        const canIR    = document.getElementById('canvas_ir');
        const ctxIR    = canIR.getContext('2d');
        const canResp = document.getElementById('canvas_resp');
        const ctxResp = canResp.getContext('2d');

        function resizeCanvases() {
            canIR.width    = canIR.parentElement.clientWidth  - 16;
            canIR.height   = canIR.parentElement.clientHeight - 16;
            canResp.width  = canResp.parentElement.clientWidth  - 16;
            canResp.height = canResp.parentElement.clientHeight - 16;
        }
        window.addEventListener('resize', resizeCanvases);
        resizeCanvases();

        var gateway   = 'ws://' + window.location.hostname + ':81/';
        var websocket;
        var statusDot  = document.getElementById('status-dot');
        var roleLabel  = document.getElementById('client-role');

        // ── Respiratory sensor signal conditioning ────────────────────────────
        // Matches the processing applied in Py_VitalSigns_DAQ.py (update_gui Step 2b).
        // The firmware sends raw ADC counts (0-1023); this JS converts to mV,
        // removes the DC baseline (animal weight offset), and optionally inverts
        // so that inspiratory peaks are positive.
        //
        // INVERT_RESP: true  = FSR406 or piezo where inspiration is a voltage drop.
        //              false = piezo where inspiration is already a voltage rise.
        const ADC_MV      = 5000.0 / 1023.0;   // 10-bit, 5 V ref: ~4.8875 mV/count
        const INVERT_RESP = true;               // change to false if peaks already positive
        const IIR_ALPHA   = 0.005;              // fc ≈ 0.08 Hz @ 25 Hz (secondary stream)
        var   respDc      = null;               // IIR DC baseline estimate

        function processResp(pzRaw) {
            var mV = pzRaw * ADC_MV;
            if (respDc === null) respDc = mV;   // initialise on first sample
            respDc += IIR_ALPHA * (mV - respDc);
            var ac = INVERT_RESP ? (respDc - mV) : (mV - respDc);
            return ac + respDc;
        }

        function initWebSocket() {
            websocket = new WebSocket(gateway);

            websocket.onopen = function() {
                statusDot.classList.add('connected');
            };

            websocket.onclose = function() {
                statusDot.classList.remove('connected');
                roleLabel.textContent = '';
                // Automatic reconnection after 3 s (handles board resets mid-session).
                setTimeout(initWebSocket, 3000);
            };

            websocket.onmessage = onMessage;
        }

        function onMessage(event) {
            // The server prefixes the payload with a role tag before the JSON:
            //   "P:" → this client is primary   (100 Hz)
            //   "S:" → this client is secondary  (25 Hz)
            // The tag is stripped before JSON parsing so the dashboard logic
            // does not need to know about the server-side dispatch strategy.
            var raw = event.data;
            var role = raw.substring(0, 2);
            var json = raw.substring(2);

            if (role === 'P:') {
                roleLabel.textContent = 'PRIMARY — 100 Hz';
                roleLabel.style.color = '#0f0';
            } else if (role === 'S:') {
                roleLabel.textContent = 'SECONDARY — 25 Hz';
                roleLabel.style.color = '#666';
            } else {
                // Fallback: no role prefix (should not occur in normal operation)
                json = raw;
            }

            try {
                var obj = JSON.parse(json);

                document.getElementById('val_hr').innerHTML =
                    (obj.hr > 0 ? obj.hr : '--') + ' <span class="unit">bpm</span>';
                document.getElementById('val_spo2').innerHTML =
                    (obj.sp > 0 ? obj.sp : '--') + ' <span class="unit">%</span>';
                document.getElementById('val_rr').innerHTML =
                    (obj.rr > 0 ? obj.rr : '--') + ' <span class="unit">rpm</span>';
                document.getElementById('val_temp').innerHTML =
                    (obj.t > 0 ? obj.t.toFixed(1) : '--.-') + ' <span class="unit">°C</span>';

                bufIR.push(obj.ir);    bufIR.shift();
                bufResp.push(processResp(obj.pz)); bufResp.shift();

                requestAnimationFrame(drawCharts);

            } catch (e) {
                console.warn('JSON parse error:', json, e);
            }
        }

        function drawSingleChart(ctx, canvas, buffer, color, minRange) {
            ctx.clearRect(0, 0, canvas.width, canvas.height);
            let maxVal = Math.max(...buffer);
            let minVal = Math.min(...buffer);
            if ((maxVal - minVal) < minRange) {
                let centre = (maxVal + minVal) / 2;
                maxVal = centre + minRange / 2;
                minVal = centre - minRange / 2;
            }
            const range = maxVal - minVal;
            ctx.beginPath();
            ctx.strokeStyle = color;
            ctx.lineWidth   = 2;
            ctx.lineJoin    = 'round';
            const stepX = canvas.width / (maxPoints - 1);
            for (let i = 0; i < maxPoints; i++) {
                const x = i * stepX;
                const y = canvas.height - ((buffer[i] - minVal) / range) * canvas.height;
                if (i === 0) ctx.moveTo(x, y);
                else         ctx.lineTo(x, y);
            }
            ctx.stroke();
        }

        function drawCharts() {
            drawSingleChart(ctxIR,    canIR,    bufIR,    '#b30000', 100);   // IR-PPG (red)
            drawSingleChart(ctxResp,  canResp,  bufResp,  '#cca300', 50);   // Respiratory (gold) — minRange 50 mV
        }

        initWebSocket();
    </script>
</body>
</html>
)rawliteral";

// ════════════════════════════════════════════════════════════════════════════
//  webSocketEvent()
//  Callback registered with webSocket.onEvent(). Called by the WebSocket
//  library for every client state change: connect, disconnect, and data.
//
//  Responsibilities:
//    - Assign the primary client slot on first connection.
//    - Clear the primary slot when the primary client disconnects, allowing
//      the next connection to take over as primary automatically.
// ════════════════════════════════════════════════════════════════════════════

void webSocketEvent(uint8_t clientId, WStype_t type,
                    uint8_t* payload, size_t length)
{
    switch (type) {

        case WStype_CONNECTED:
            // Assign primary role to the first client that connects.
            // Subsequent clients are automatically secondary.
            if (primaryClientId == NO_PRIMARY) {
                primaryClientId = clientId;
            }
            break;

        case WStype_DISCONNECTED:
            // If the primary disconnects, clear the slot.
            // The next packet dispatch will skip this ID (not connected),
            // and the next client to connect will become primary.
            if (clientId == primaryClientId) {
                primaryClientId = NO_PRIMARY;
            }
            break;

        case WStype_TEXT:
        case WStype_BIN:
            // Browser-to-server messages are not expected in this application.
            // Ignore silently.
            break;

        default:
            break;
    }
}


// ════════════════════════════════════════════════════════════════════════════
//  dispatchPacket()
//  Sends the current JSON payload to all connected WebSocket clients using
//  the tiered rate strategy:
//
//    Primary client   → every packet           (100 Hz)
//    Secondary clients → every SECONDARY_DIVISOR-th packet (25 Hz at /4)
//
//  A role prefix is prepended to the payload so the browser can identify
//  its own dispatch tier and display it in the UI:
//    "P:<json>"  — sent to the primary client
//    "S:<json>"  — sent to secondary clients
//
//  The prefix adds 2 bytes per packet — negligible overhead.
// ════════════════════════════════════════════════════════════════════════════
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
void loop()
{
    // WebSocket and HTTP service calls — must execute every iteration.
    // Any blocking code between these calls degrades client responsiveness.
    webSocket.loop();
    server.handleClient();

    // ── Non-blocking Serial receive ───────────────────────────────────────────
    // Reads one byte per loop() call and appends to rxBuffer.
    // When '\n' is received, the complete JSON line is ready for dispatch.
    //
    // Why non-blocking matters with multiple clients:
    //   The WebSocket library must call webSocket.loop() frequently to process
    //   keep-alive (ping/pong) frames from each connected browser. With 5 clients
    //   each sending a ping every ~15 s, the library needs to respond within the
    //   ping timeout (~30 s). As long as webSocket.loop() is called at least
    //   once per second, this is satisfied. The non-blocking read guarantees
    //   webSocket.loop() runs every loop() iteration regardless of Serial state.
    while (Serial.available()) {
        char c = (char)Serial.read();

        if (c == '\n') {
            // End of packet — process the accumulated line
            rxBuffer.trim();   // Remove '\r' if present (Windows line endings)

            if (rxBuffer.length() > 2) {
                dispatchPacket(rxBuffer);
            }

            rxBuffer = "";   // Reset for next packet
        } else {
            rxBuffer += c;

            // Guard against a runaway buffer if '\n' never arrives
            // (e.g., Mega reset mid-packet). 128 bytes >> max packet length (~65 B).
            if (rxBuffer.length() > 128) {
                rxBuffer = "";
            }
        }
    }
}

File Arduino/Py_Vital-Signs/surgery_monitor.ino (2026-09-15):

/**
 * @file    surgery_monitor.ino
 * PROJECT: Vital-signs monitor — small rodents (rat / mouse)
 * @version 1.0
 * @author  Flávio Mourão — Mar, 2026
 *
 * ═══════════════════════════════════════════════════════════════════════════════
 * DESCRIPTION
 * ═══════════════════════════════════════════════════════════════════════════════
 * Real-time, non-invasive physiological monitoring during prolonged experimental
 * surgeries, stereotaxic procedures, and deep anaesthesia protocols in rodents.
 *
 * ═══════════════════════════════════════════════════════════════════════════════
 * HARDWARE SCALABILITY
 * ═══════════════════════════════════════════════════════════════════════════════
 *
 * [ PORTABLE — UNO / NANO ]
 *   MCU        : ATmega328P  |  16 MHz  |  2 KB SRAM
 *   Parameters : Respiratory Rate (piezo belt) + Core Temperature (NTC)
 *   Limitation : Insufficient SRAM for MAX30102 buffers (800 B needed vs ~348 B
 *                available after static allocations). Do NOT enable MAX30102 here.
 *
 * [ FULL MULTIPARAMETRIC — MEGA 2560 ]
 *   MCU        : ATmega2560  |  16 MHz  |  8 KB SRAM
 *   Parameters : HR + SpO2 (MAX30102) + Respiratory Rate + Core Temperature
 *   SRAM usage : ~800 B buffers + ~900 B firmware = ~1700 B / 8192 B (21%)
 *
 * ═══════════════════════════════════════════════════════════════════════════════
 * SYSTEM ARCHITECTURE
 * ═══════════════════════════════════════════════════════════════════════════════
 *
 * Two execution layers, strictly decoupled:
 *
 * ┌──────────────────────────────────────────────────────────────────────────┐
 * │  INTERRUPT LAYER  (hard real-time)                                       │
 * │                                                                          │
 * │  ADC_vect  (~9.6 kHz, free-running)                                      │
 * │    4-state MUX sequencer alternates between A0 (piezo) and A1 (NTC).     │
 * │    States 1 and 3 discard the conversion in flight during MUX switching  │
 * │    (ATmega datasheet requirement: one dummy conversion after ADMUX        │
 * │    change before result is valid).                                        │
 * │    Effective rates:  piezo → ~9.6 kHz raw,  NTC → ~10 Hz                 │
 * │                                                                          │
 * │  TIMER1_COMPA_vect  (100 Hz, CTC mode, prescaler 64, OCR1A = 2499)       │
 * │    Decimates piezo from 9.6 kHz → 100 Hz via N=4 moving average.         │
 * │    Runs hysteresis peak detector for respiratory rate.                   │
 * │    Maintains RR ring buffer (N=4 intervals, power-of-2 for shift-divide).│
 * └──────────────────────────────────────────────────────────────────────────┘
 *
 * ┌──────────────────────────────────────────────────────────────────────────┐
 * │  MAIN LOOP LAYER  (cooperative, millis()-based scheduling)               │
 * │                                                                          │
 * │  Task 1 — Threshold calibration    every 2 s                             │
 * │  Task 2 — Temperature conversion   every 1 s                             │
 * │  Task 3 — MAX30102 HR + SpO2       every loop() call (non-blocking)      │
 * │  Task 4 — OLED display             ~30 FPS (33 ms)                       │
 * │  Task 5 — ESP8266 vital signs stream  100 Hz via Serial3                  │
 * │  Task 6 — Python USB stream + config  100 Hz out / on-demand in           │
 * └──────────────────────────────────────────────────────────────────────────┘
 *
 * SHARED VARIABLE PROTOCOL
 *   All variables written by an ISR and read by the main loop are declared
 *   volatile. Multi-byte reads in the main loop use noInterrupts()/interrupts()
 *   critical sections to prevent torn reads (AVR has no atomic 16/32-bit ops).
 *
 * TIMING DEPENDENCY
 *   millis() is driven by TIMER0_OVF_vect. TIMER1_COMPA_vect masks global
 *   interrupts during execution (~10-15 us). This is well below the 1 ms
 *   TIMER0 period, so millis() drift is negligible. If TIMER1_COMPA_vect
 *   execution ever exceeds ~900 us, permanent millis() drift will occur.
 *
 * ═══════════════════════════════════════════════════════════════════════════════
 * DISPLAY LAYOUT  (SSD1306, 128x32 px, I2C)
 * ═══════════════════════════════════════════════════════════════════════════════
 *
 *  col 0              col 61          col 127
 *  ┌──────────────────┬───────────────────────┐  row 0
 *  │ HR  : 350        │ RR: 85                │  row 9
 *  │ Sat%: 98         ├───────────────────────┤  row 14
 *  │ Temp: 37.2       │  respiratory waveform │  row 31
 *  └──────────────────┴───────────────────────┘
 *
 * ═══════════════════════════════════════════════════════════════════════════════
 * TARGET HARDWARE
 * ═══════════════════════════════════════════════════════════════════════════════
 *  MCU     : ATmega2560 — Arduino Mega 2560, 16 MHz, 8 KB SRAM
 *  Display : SSD1306 OLED, 128x32, I2C @ 400 kHz (address 0x3C)
 *  Piezo   : Respiratory belt → A0
 *  NTC     : 100 kOhm rectal thermistor → A1
 *            Circuit: VCC — R_FIXED(100 kOhm) — A1 — NTC — GND
 *  MAX30102: HR + SpO2 optical sensor → I2C (shared bus)  [MEGA ONLY]
 *  ESP8266 : Wi-Fi AP + WebSocket server (RobotDyn on-board co-processor)
 */

#include <U8g2lib.h>
#include <Wire.h>
#include <math.h>

// MAX30102 includes and extern declarations live in surgery_monitor_MAX30102.ino.
// The Arduino IDE merges all .ino files in the sketch folder before compiling,
// so no #include is needed here. The extern declarations below give this
// translation unit access to the shared output variables.
extern int heartRate;   // BPM — written by MAX30102 module, read by display task
extern int spO2;        // %   — written by MAX30102 module, read by display task

// Functions defined in surgery_monitor_MAX30102.ino
extern bool     max30102_init();
extern void     max30102_update();
extern uint32_t max30102_getIR();
extern bool     max30102_set_param(const String& key, float value);

// Vital Signs Streaming — ESP8266 bridge
extern void vitalsigns_init();
extern void vitalsigns_update();

// Vital Signs Streaming — Python code USB
extern void py_vital_signs_init();
extern void py_vital_signs_update();

// ═══════════════════════════════════════════════════════════════════════════════
//  DISPLAY DRIVER
// ═══════════════════════════════════════════════════════════════════════════════

// U8G2_R0 = no rotation. U8X8_PIN_NONE = no hardware reset pin used.
// HW_I2C uses the hardware I2C peripheral (pins 20/21 on Mega 2560).

U8G2_SSD1306_128X32_UNIVISION_F_HW_I2C u8g2(U8G2_R0, U8X8_PIN_NONE);


// ═══════════════════════════════════════════════════════════════════════════════
//  HARDWARE PINS AND ADC CHANNEL CODES
// ═══════════════════════════════════════════════════════════════════════════════
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
